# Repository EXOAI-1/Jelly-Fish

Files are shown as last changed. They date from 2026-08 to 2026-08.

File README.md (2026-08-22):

# EXO-MEDUSA — consumer print kit (Bambu Lab A1)

**Aquarium jellyfish · Ø280 × 380 mm · 360° servo · phone remote over Wi-Fi AP · 2 weekends**

This folder is the printable kit for a **Bambu Lab A1** (256 × 256 × 256 mm, 0.4 mm nozzle).
It is a dry-capsule magnetic-drive jelly: a 3-lobe cam pumps a sliding ring that bends
eight Fin-Ray tentacles in unison. No electronics in the water.

| | |
|---|---|
| Size in the tank | about **Ø 280 mm** bell, **380 mm** long |
| Printer assumed | **Bambu Lab A1**, 0.4 mm nozzle, textured PEI |
| Drive | **360° continuous servo** (DS04-NFC or MG996R 360) — not a brushless motor |
| Brain | ESP32-C3 SuperMini, SoftAP **`EXO-MEDUSA`** / `medusa123` → http://192.168.4.1 |
| Time | **2 weekends** once parts are printed (print itself is several overnight jobs) |
| Default tentacles | **TPU 95A skeleton ×8 + 0.3 mm PET film + PETG barrette ×8** |

## What's in the box

```
EXO-MEDUSA-kit/
  README.md                 ← you are here
  PARTS.csv                 file / qty / material / plate / notes
  print/
    BAMBU_A1.md             exact slicer starting points (official A1 presets)
    plates.md               how to split the bed: magnet-test → structure → TPU → dome
    EXO-MEDUSA_A1.3mf       all default STLs as named objects (open in Bambu Studio)
    stl/                    one file per part (consumer names)
    stl/aliases/            original engineering filenames (hardlinks)
    stl/optional/           OLD clamp / rib / paddle tentacle system — not the default
  docs/
    BOM.md                  buy list (Thailand), servo not Furitek
    GABARIT_FLANCS_1-1.pdf  1:1 PET-film cutting template (print at 100 %)
    TENTACLES.md            why piece 19/20 were reconstructed
  scad/                     medusa_v6, dome_flotteur, tentacle skeleton + barrette
  firmware/                 flash notes + sketch (do not start here — print first)
```

**Not in this kit (on purpose):** silicone “flesh” molds (`22_moule_*`) and the Festo AquaJellies brochure.

## Two-weekend build

**Before weekend 1 — print, in this order** (see `print/plates.md`):

1. **Magnet-test plate:** parts **01, 03, 04, 05, 07**. Glue magnets, confirm the two rotors *attract* through ~3 mm of PETG. If this fails, stop — do not print the rest yet.
2. **Structure plate:** 02 fuselage, 06 cam, 08 stator (Tree Slim supports), 09 slider, 18 ballast, 20 barrettes ×8.
3. **TPU plate:** 19 skeletons ×8 at **30 mm/s**. Print **one** first, overlay the gabarit, then the other seven.
4. **Transparent plates:** 13 dome alone, then disk + apex plug.

**Weekend 1:** magnets, axle, stator, servo in the can, cam + slider, dry pulse.

**Weekend 2:** cut 8 PET films, glue tentacles (TPU + film + barrette), hang on both rings, wire + flash, O-ring the fuselage, seal the float 24 h, 24 h capsule leak test, trim ballast, tank swim.

Assembly steps live in the notice PDF (another document). This kit is the **print + buy** front door.

## Print at a glance

| Group | Material | Parts | A1 bed |
|---|---|---|---|
| 1 magnet-test | PETG | 01, 03, 04, 05, 07 | **one plate**, all fit |
| 2 structure | PETG | 02, 06, 08, 09, 18, 20×8 | **one plate**, all fit |
| 3 TPU | TPU 95A | 19 ×8 | **one tight plate** or two of 4 |
| 4 dome | Transparent PETG | 13 dome | **own plate** (Ø160 mm) |
| 5 dome seal | Transparent PETG | 13 disk + plug | **own plate** (disk Ø145 + dome Ø160 cannot share a 256 mm bed) |

No default part exceeds 256 mm in X, Y, or Z.

Filament to buy: **1 kg PETG** (structure ~300 g printed + brim/purge/failed magnet-test), **~200 g transparent PETG** (dome + solid disk), **~50–80 g TPU 95A** (8 skeletons + brim). Official notice ballpark was 450 / 95 / 60 g — the disk is a Ø145 × 3 mm plate, so transparent mass is higher than that ballpark.

## Default vs optional tentacles

- **Default (this kit):** TPU skeleton `19_tentacle_skeleton_TPU_x8.stl` + PET 0.3 mm from the gabarit + PETG barrette `20_tentacle_bar_PETG_x8.stl`.
- **Do not print** `21_flanc_superieur_TPU` as piece 19 (wrong geometry). It is parked under `print/stl/optional/`.
- **Optional / old path:** `print/stl/optional/clamp_old_x16.stl` + `rib_old_x40.stl` + `paddle_old_x8.stl` exported from `medusa_v6.scad`. Only if you abandon the notice.

## Phone remote

After flash: join Wi-Fi **EXO-MEDUSA** / **medusa123**, open **http://192.168.4.1**. BLE Nordic UART still speaks `V50`, `V-40`, `S`, `A`, `?`, `R`. Autonomous default is 8 s swim / 4 s glide at 42 %.

## Safety (short)

N52 magnets: pinch, shatter, **lethal if swallowed**. 18650: no shorts, charge only via TP4056. CA glue: seconds. Servo 5 V from the boost, **not** through the ESP32. Wet-side magnets must be varnished. Unsealed dome → the robot inverts.

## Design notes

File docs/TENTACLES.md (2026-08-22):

# EXO-MEDUSA tentacles — TPU + PET film path (v6.2 / gabarit v6.3)

Status after this pass: **CONDITIONAL GO**. The original zip could not print notice
tentacles. This folder now has a reconstructed piece 19 + piece 20. Print **one**
TPU skeleton first, overlay the 1:1 gabarit, then print the remaining seven.

Do **not** use `21_flanc_superieur_TPU_x8.stl` as piece 19. Do **not** pour the
`22_moule_chair_silicone*.stl` trays. Do **not** print `medusa_v6.scad` clamp/rib/paddle
unless you abandon the notice path.

---

## 1. Notice quotes (étapes 0, 0b, 9, 10)

**Étape 0 — print table**

| Pièce | Orientation | Réglages |
|---|---|---|
| 19 Squelettes TPU ×8 | à plat | TPU 95A, 30 mm/s maxi, 1-2 plateaux |
| 20 Barrettes ×8 | à plat | PETG, 1 plateau |

**Étape 0b — film** (page 3): *« Chaque tentacule n'a besoin que d'UNE pièce de
film PET 0,3 mm, d'une forme simple (long trapèze + queue de poisson) : 8
découpes identiques avec le gabarit fourni (GABARIT_FLANCS_1-1.pdf). »*
Print gabarit at 100 %, control square **50,0 mm**. *« Le petit téton du bas
sera collé sur la barrette imprimée. »* Mark dashed **B1–B6** before peeling.
Qty: **8 identical films** (title says “16 flancs”; body text and gabarit
v6.3 say one film per tentacle).

**Étape 9**: *« Chaque tentacule = 1 squelette TPU imprimé (pièce 19) + 1 film
(étape 0b) + 1 barrette (pièce 20). »* Glue **14 pads** only, not spine, not
bars. Film marks B1–B6 facing the bars. Film teton into barrette **cuvette**.
*« zéro nervure à enfiler. »* Finger-press test: must curve **toward** the
finger (Fin-Ray).

**Étape 10 — hang on both rings**

1. **Anneau FIXE** (stator top): barrette teton from **below** into 8 slots + cyano.
   Films now hang from the frame.
2. **Anneau COULISSANT**: TPU skeleton teton from **below** into its 8 slots + cyano.
3. Order: 8 barrettes first → cam to sliding ring **LOW** → then skeletons.
4. Ring down → tentacles curve **inward** (power stroke), all eight together.

Curvature tweak (missing file): `tentacule_v62.scad` `sp_t = 2.6` (too soft) /
`sp_t = 1.8` (too stiff). *« 2 mm de jeu à la racine mangent la moitié de la
course. »*

---

## 2. Gabarit film — measured from PDF vectors (1 pt = 25.4/72 mm)

`GABARIT_FLANCS_1-1.pdf` page content stream, left outline. Control rectangle
width **50.00 mm**. Two copies of the same outline on one A4.

| Feature | Size (mm) |
|---|---|
| Total length (teton bottom → fishtail tip) | **212.0** |
| Root teton (glues in barrette cuvette) | **12.0 × 12.0** |
| Shoulder above teton | **16.0 wide × 40.0** |
| Main body | **30.0 wide × 126.0** |
| Fishtail outer width / tip height | **36.0 / 34.0** |
| PET thickness | **0.3** (notice + gabarit text) |
| Qty | **8** (1 per tentacle; 2 outlines/sheet) |

**B1–B6** (from teton bottom, pitch **22.40 mm**): 60.0, 82.4, 104.8, 127.2,
149.6, 172.0. Gabarit: *« ce sont les 6 lames du squelette — le film se presse
sur leur chant encollé. »* Notice étape 9 instead glues **square pads at bar
tips**. Use the notice method (pads only).

---

## 3. Part-19 verdict: `21_flanc_superieur_TPU_x8.stl` is **NOT** pièce 19

ASCII OpenSCAD mesh, 68 triangles / 36 unique vertices. Bounding box
**22.000 × 209.000 × 7.400 mm** (`x=-11..11, y=-7..202, z=0..7.4`).

Reconstructed solids:

| Feature | Size (mm) |
|---|---|
| Root plate | 22 × 14 × 3.2 |
| Male slot tab | **8.0 × 2.8 × 4.2** (z=3.2..7.4) — same as `clamp()` in `medusa_v6.scad` |
| Spine | 4.0 wide × 175 long × 2.2 thick (y=7..182) |
| Fishtail paddle | 18 wide × 20 long × 1.6 (vertices ±9,198 / 0,202) |
| Holes / slots / crossbars / pads | **none** |

Notice pièce 19 is a Fin-Ray **ladder**: spine + 6 blades + square pads + TPU
teton into the **sliding** ring. File 21 is a one-piece TPU **upper flank**
(strip + paddle + ring tab). Same tentacle scale (~210 mm), different
mechanism. Ignore 21 for the notice path.

---

## 4. `medusa_v6.scad` vs barrette / `tentacule_v62.scad`

`medusa_v6.scad` parts: `cam3 | slider | stator | clamp | rib | paddle`.
**No barrette.** Universal slots `slot_w=8.6; slot_t=3.0`. Clamp is a 14×10×12
PET-film pincer with 0.55 mm slit + 8×2.8×4.2 tab (×16). Rib ×40 comb,
paddle ×8. That is the **older two-flank clamp/rib/paddle** path. No STLs were
exported for those three. **`tentacule_v62.scad` is not anywhere in this zip.**

---

## 5. Silicone molds — ignore for tank-swim

| File | BBox (mm) |
|---|---|
| `22_moule_chair_silicone.stl` | 58 × 236 × 7.6 (cavity floor z≈2.99, rim 7.6) |
| `22_moule_chair_silicone (1).stl` | 58 × 244 × 7.6 (richer, not a byte copy) |

Notice never pours silicone on tentacles. Not pièce 19/20.

---

## 6. What to print now

| File | Qty | Material | Notes |
|---|---|---|---|
| `19_squelette_TPU_x8.stl` | 8 (print 1 first) | **TPU 95A**, 30 mm/s, à plat, pads+teton up | Reconstruction — see parameters |
| `20_barrette_PETG_x8.stl` | 8 | **PETG**, à plat, teton up | Reconstruction — cuvette 12.8×12.8×0.8 |
| PET film from gabarit | 8 | PET 0.3 mm A4 | Cut solid line; mark B1–B6 |
| `21_flanc_superieur_TPU_x8.stl` | 0 | — | **Not** piece 19 |
| `22_moule_chair_silicone*.stl` | 0 | — | Ignore |
| clamp / rib / paddle | 0 | — | Only if abandoning notice path |

### Piece 19 defaults (reconstruction)

| Param | Default | Source |
|---|---|---|
| Spine `sp_t` × `sp_w` | **2.2 × 4.0** | part 21 spine; NOTICE 1.8–2.6 band |
| Bars | **6** at pitch **22.4** | gabarit B1–B6 |
| `ring_sep` | **36** | EST from rotor z~174 / cam groove ~154 / stator ring z190 |
| `b1_y` | **24** | 60 (gabarit B1) − 36 |
| Bar span | **30** | gabarit body width |
| Pads | **3.5** sq × **1.4** rise, ×12 | EST (NOTICE says 14; gabarit has 6 blades → 12) |
| Teton | **8.0 × 2.8 × 6.2** | slot family + slider `sl_t=6` |
| Root plate | 12 × 10 × 3.2 | part 21 thickness 3.2 |
| Overall (defaults) | **30 × 154 × 9.4** | span × (root+spine) × (root 3.2+teton 6.2) |

OpenSCAD was **not** available (`apt: Unable to locate package openscad`).
The STL is a cube-union of these defaults. Edit `19_squelette_TPU_x8.scad`
and re-export on your machine after the first dry-fit.

### Piece 20 defaults

| Param | Default | Source |
|---|---|---|
| Teton | **8.0 × 2.8 × 4.5** | slot family; stator `ring_t=4` + 0.5 glue |
| Cuvette | **12.8 × 12.8 × 0.8** | gabarit 12×12 teton + 0.4/side |
| Body | **18 × 20 × 3.2** | 12 mm tab + walls; part 21 plate thickness |
| Overall | **18 × 20 × 7.7** | body 3.2 + teton 4.5 |

---

## 7. Cut-from-gabarit steps

1. Print `GABARIT_FLANCS_1-1.pdf` at **100 % / actual size**. Measure the
   control box: **50.0 mm** wide. Reprint if not.
2. Stick the sheet on 0.3 mm PET (repositionable spray or corner tape).
   One A4 = two outlines → two films.
3. Cut the **solid** line with cutter + metal rule. Keep the 12×12 mm teton
   intact.
4. Before peeling, mark **B1–B6** with a fine pen (22.4 mm pitch, first mark
   60 mm from teton bottom).
5. Repeat to **8** films. Fold test: no white crease (that would be PS, not PET).

---

## 8. Table assembly (étape 9) then hang (étape 10)

1. Skeleton flat, **pads up**. One CA drop on each pad (12 with this mesh;
   notice says 14). None on spine, none on bars.
2. Press film on in one go, B1–B6 on the bars, centred on the spine. 10 s palm.
3. Glue film 12×12 teton into barrette cuvette (blob of CA, 10 s).
4. Hang **barrettes** in the 8 stator slots from below, cyano. Cam to ring LOW.
   Then hang **skeleton tetons** in the 8 sliding-ring slots from below, cyano.
5. Dry test: turn cam by hand — eight tentacles curl inward together.

If bars miss the B marks: change `ring_sep` (hence `b1_y`) and reprint one
skeleton. If too floppy/stiff: `sp_t = 2.6` / `1.8`.

---

## 9. Go / no-go

| Question | Answer |
|---|---|
| Could they print notice tentacles **from the original zip**? | **NO-GO.** Piece 19 missing (21 is the wrong geometry). Piece 20 missing. Gabarit present. |
| Can they print tentacles **from this folder now**? | **CONDITIONAL GO.** Print 1× TPU 19 + 1× PETG 20 + 1 film, overlay gabarit, then ×8. |
| Piece 19 origin | Reconstruction (no `tentacule_v62.scad`). Parameters labeled. |
| Piece 20 origin | Reconstruction from gabarit teton + proven 8.0×2.8 slot tab. |
| Silicone / clamp-rib-paddle | Not required for first tank swim. |

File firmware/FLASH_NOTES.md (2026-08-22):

# EXO-MEDUSA v5 — flash notes (tank swim)

Board in Arduino IDE: **ESP32C3 Dev Module** (ESP32-C3 SuperMini).
Notice étape 11b: **USB CDC On Boot = Enabled**.

## Install (notice étape 11b)

1. Arduino IDE from arduino.cc
2. File → Preferences → Additional boards manager URLs:
   `https://espressif.github.io/arduino-esp32/package_esp32_index.json`
3. Boards Manager: install **esp32 by Espressif Systems** (current 3.x is fine; sketch also falls back to 2.x LEDC)
4. Tools → Board → esp32 → **ESP32C3 Dev Module**
5. Tools → **USB CDC On Boot = Enabled**
6. USB-C data cable, pick the port. If none: hold **BOOT** while plugging in, then release.
7. Open `firmware_medusa.ino` → Upload. Success looks like “Hash of data verified” / “Done uploading”.
   Failed to connect: BOOT trick again.

The notice does **not** specify flash size, frequency, partition scheme, or upload speed. Leave Arduino defaults (typically 80 MHz, QIO, 4 MB, Default 4 MB with spiffs, 921600). SuperMini is usually 4 MB.

## Libraries

- **ENABLE_LED 0 (default, tank swim):** no extra library. Built-in WiFi / BLE / LEDC only.
- If you later set `ENABLE_LED 1`: install **Adafruit NeoPixel**, **and move leak off GPIO4** (WS2812 uses GPIO4).

## Pin table (v5)

| Function | GPIO | Notes |
|---|---|---|
| Servo PWM (360° continuous) | **10** | 50 Hz, 16-bit LEDC, 1500 µs stop, ±100% → ±500 µs |
| Reed / ILS | **3** | INPUT_PULLUP to GND. Tap = run/stop or fault reset; 3 s = deep sleep |
| NTC 10k B3950 | **0** | ADC1. 10k to 3.3 V, NTC to GND |
| Vbat divider | **1** | ADC1. 100k/100k from pack + |
| Hall SS49E | **2** | ADC1. 3.3 V / GND / signal |
| Leak probe | **4** | ADC1. Was GPIO5 (not ADC on C3). 2 bare wires + 470k to 3.3 V. Analog threshold `<1200` |
| WS2812 ring | 4 (ifdef) | Off by default. Do not enable while leak is on GPIO4 |

Wi-Fi AP still `EXO-MEDUSA` / `medusa123`, page `http://192.168.4.1`. BLE Nordic UART unchanged (`V50`, `V-40`, `S`, `A`, `?`, `R`).

Rewire the leak sense from GPIO5 (notice étape 11) to **GPIO4**.

## Servo rail

Keep **470 µF** across the servo 5 V rail (long leg on +), fed from the boost, **not** through the ESP32. Brown-outs make the servo twitch without turning.

## After flash

Autonomous cycle: 8 s swim / 4 s glide at 42%. Then 24 h dry capsule leak test before a tank swim.

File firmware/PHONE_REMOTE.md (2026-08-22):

# EXO-MEDUSA phone remote (v6 kit)

The jellyfish is its own Wi-Fi access point. Your **phone browser is the remote**. No app to install. BLE remains a backup.

SoftAP: **EXO-MEDUSA** / **medusa123** → **http://192.168.4.1**

There is **no internet** on this network. That is normal. Stay on EXO-MEDUSA; the page is served by the ESP32.

## iPhone (Safari)

1. Settings → Wi-Fi → join **EXO-MEDUSA**, password **medusa123**.
2. iOS may pop a **“Log in”** captive-portal page. That *is* the remote — use it. Do not tap **Cancel** / **Use without internet** if you want the page to stay.
3. If nothing pops: open Safari and type **http://192.168.4.1** (type the address, do not search Google).
4. If Safari cannot open the page: toggle Wi-Fi off/on, rejoin, try the URL again. Turn off VPN / iCloud Private Relay for this network if DNS is hijacked.
5. Optional: Share → **Add to Home Screen** for a full-screen remote. Still just the browser.

## Android (Chrome)

1. Wi-Fi → join **EXO-MEDUSA**, password **medusa123**.
2. Android will often say **“Connected without internet”**. Stay on this network — tap the network → disable auto-switch to mobile data if the phone hops away.
3. A **Sign in to network** banner may appear — open it. Otherwise Chrome → **http://192.168.4.1**
4. If Chrome searches instead of loading: type `http://` in front of the address.

## Controls

| Control | Command |
|---|---|
| **SWIM** | Forward 55% (remote; auto resumes after 120 s idle) |
| **STOP** | Speed 0 |
| **AUTO** | Built-in 8 s swim / 4 s glide at 42% |
| **REV** | Reverse nudge (−35%) |
| Slider | −100% … +100% |
| **RESET FAULT** | Clears a fault if the leak is gone |

Live tiles (temp °C, battery V, RPM, mode, fault) poll `/status` every 1 s. No 4-second page refresh.

## BLE backup

If the AP is flaky: Android **Serial Bluetooth Terminal** (Bluetooth LE tab) or iPhone **BLE Terminal**. Device name `EXO-MEDUSA`. Text: `V50`, `V-40`, `S`, `A`, `?`, `R`. Last order wins (Wi-Fi or BLE).

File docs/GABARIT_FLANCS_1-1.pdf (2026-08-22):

## GABARIT FILM TENTACULE v6.3 — ÉCHELLE 1:1 — imprimer à 100 % — découpe ×8

1. Vérifie le carré : 50,0 mm. 2. Colle la feuille sur le film PET 0,3. 3. Découpe le trait plein (cutter + règle). 4. Marque B1-B6 au feutre :
ce sont les 6 lames du squelette — le film se presse sur leur chant encollé. Le petit téton du bas se colle sur la barrette. UNE pièce par tentacule.

CONTRÔLE : 50,0 mm →

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
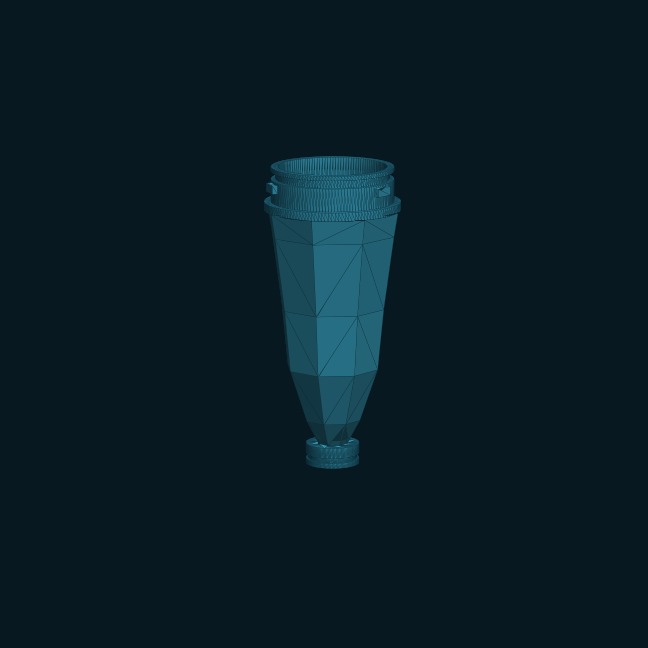
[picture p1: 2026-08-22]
docs/img/02_fuselage.png

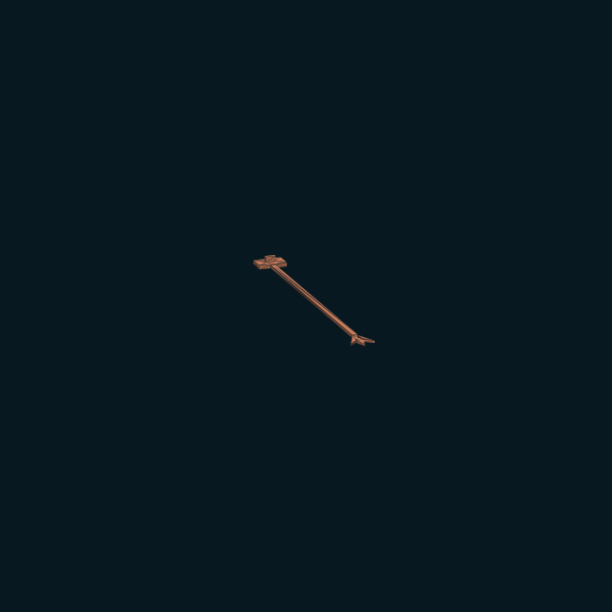
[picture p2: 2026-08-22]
docs/img/19_tpu_paddle.png

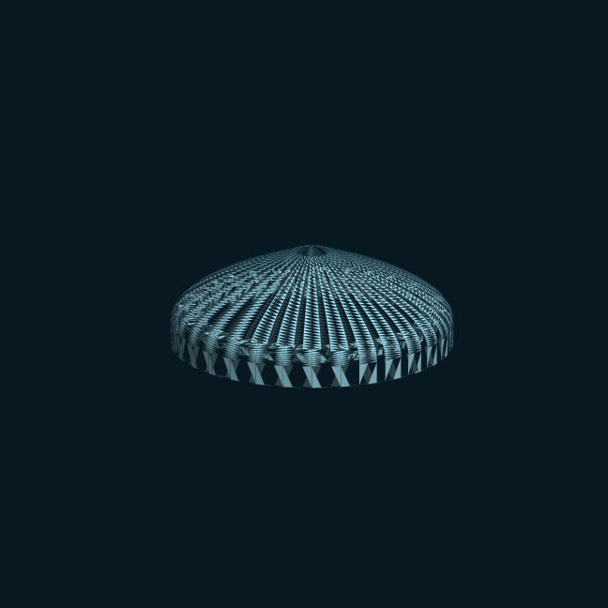
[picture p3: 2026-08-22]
docs/img/13_dome.png

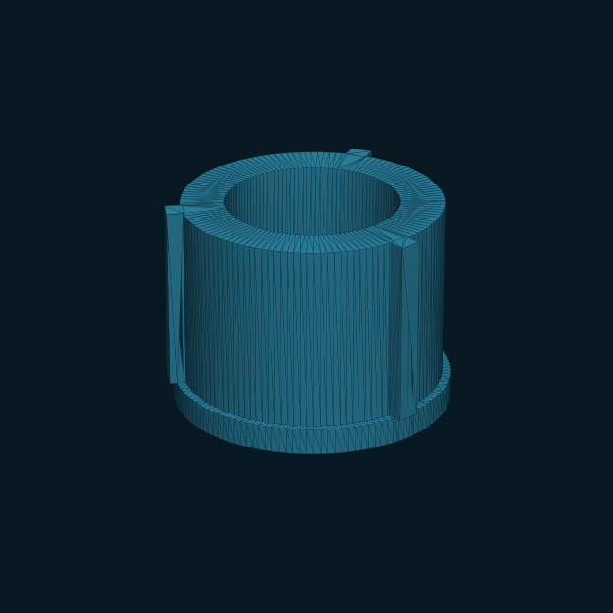
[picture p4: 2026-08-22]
docs/img/05_rotor_outer.png

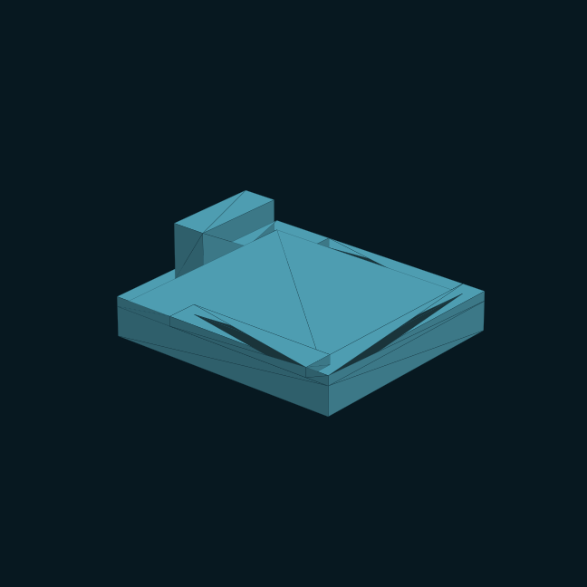
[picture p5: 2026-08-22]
docs/img/20_barrette.png

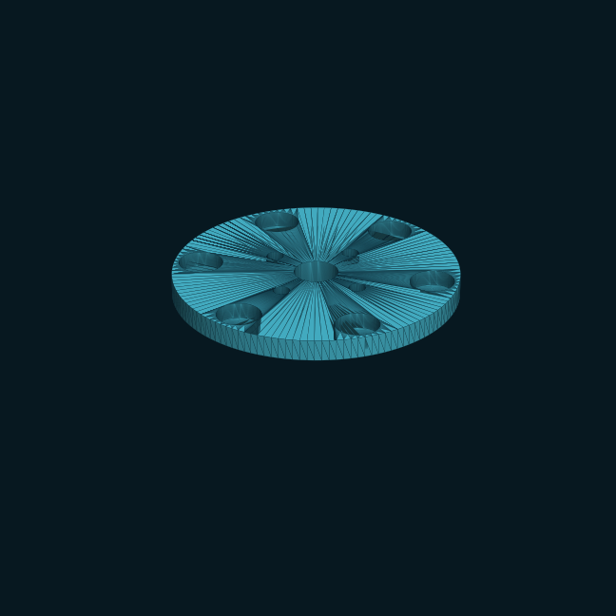
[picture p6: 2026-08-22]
docs/img/04_rotor_inner.png

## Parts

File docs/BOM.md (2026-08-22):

# EXO-MEDUSA — bill of materials (v1 tank swim)

Drive is a **360° continuous servo**, **not** the Furitek Mini-Komodo.
Skip: LED ring, SG90 pendulum, Qi wireless, silicone “flesh” molds.

Prices in THB are from `Meca_Jellyfish_BOM_Thailand.xlsx` except the servo (that spreadsheet had the wrong motor). Search column is Lazada / Shopee TH.

## Buy (electronics)

| What | Qty | Search | ~THB |
|---|---|---|---|
| 360° continuous servo (DS04-NFC or MG996R 360) | 1 | `DS04-NFC 360` or `MG996R 360 continuous` | — (not in the old BOM) |
| ESP32-C3 SuperMini | 1 | ESP32-C3 SuperMini | 105 |
| 18650 + holder (3000 mAh) | 1 | 18650 battery holder | 140 |
| TP4056 with protection (DW01) | 1 | TP4056 protection | 35 |
| 5 V boost ≥2 A (MT3608) | 1 | MT3608 boost 5V | 35 |
| 470 µF 10 V electrolytic | 1 | 470uF electrolytic | 17.5 |
| SS49E linear Hall | 1 | SS49E hall sensor | 17.5 |
| NTC 10k B3950 | 1 | NTC 10k 3950 | 17.5 |
| Reed switch + magnet | 1 | reed switch glass | 35 |
| Resistors: 10k ×1, 100k ×2, 470k ×1 | 1 kit | resistor kit | 35 |

Servo 5 V goes through the boost, **not** through the ESP32. 470 µF sits across the servo 5 V rail.

## Buy (mechanics / consumables)

| What | Qty | Search | ~THB |
|---|---|---|---|
| N52 magnets 8×3 mm | 12 | N52 8x3 magnet | 105 |
| N52 magnets 5×2 mm | 2 | N52 5x2 magnet | 35 |
| NBR O-ring ~53×3 mm | 1 | o-ring 53x3 | 35 |
| Silicone grease | 1 | silicone grease plumbing | 70 |
| PET film 0.3 mm A4 | 10 sheets | PET sheet 0.3mm A4 | 70 |
| M3 screws: 16 mm ×2, 10 mm ×3, 8 mm ×5 | 1 kit | M3 screw kit | 70 |
| Fishing sinkers / steel balls ~40 g | 1 | fishing sinkers split shot | 70 |
| Aquarium silicone 100% clear, **no fungicide** | 1–2 | aquarium silicone sealant clear 100% | 175 |
| 5-min epoxy | 1 | epoxy glue 5 minutes | 70 |
| CA glue (cyanoacrylate) | 1 | super glue CA | — (notice uses it everywhere; not in the old BOM) |
| Thermal pad + a bit of foam | 1 | thermal pad servo | — (notice étape 6) |
| Nail varnish (wet-side magnets) | 1 | — | household |

Cut the 8 tentacle films with `docs/GABARIT_FLANCS_1-1.pdf` printed at **100 %** (50.0 mm control square).

## Print (filament)

| What | ~mass (printed) | Buy | Use |
|---|---|---|---|
| PETG | ~300 g structure + bars (buy **1 kg**) | Generic PETG | capsule, stator, cam, ring, axle, rotors, barrettes ×8 |
| Transparent PETG | ~140 g (buy a small spool) | PETG Translucent | float dome + disk + plug |
| TPU 95A | ~30 g skeletons ×8 (buy **≥ 100 g**) | TPU 95A | tentacle skeletons; 30 mm/s; external spool |

Masses are STL-volume estimates; brim / purge / a failed plate are extra. The old notice ballpark (450 / 95 / 60 g) is fine as a shopping ceiling.

## Do not buy for v1 swim

- Furitek Mini-Komodo (wrong motor for this firmware)
- WS2812 8-LED ring
- SG90 (pendulum steering — v6.1, not this kit)
- Qi wireless TX/RX
- Silicone tentacle molds (`22_moule_*`)

Priced hardware rows above ≈ **1060 THB + servo + filament + CA / thermal pad**.

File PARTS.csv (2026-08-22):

file | qty | material | plate_group | bbox_mm | notes | original_name
01_capsule_upper.stl | 1 | PETG | 1_magnet_test | 66.0x66.0x66.0 | Magnet-test first. Dry capsule upper can. | 01b_bidon_sup.stl
02_fuselage.stl | 1 | PETG | 2_structure | 66.0x66.0x147.0 | O-ring groove in the collar. Do not print with 01 on first plate. | 02b_fuselage.stl
03_stub_axle.stl | 1 | PETG | 1_magnet_test | 26.0x26.0x48.5 | Magnet-test. Bolts to can roof. | 03_stub_axle.stl
04_rotor_inner.stl | 1 | PETG | 1_magnet_test | 54.0x54.0x12.0 | Magnet-test. 6× N52 8×3 pockets. | 04_rotor_inner.stl
05_rotor_outer.stl | 1 | PETG | 1_magnet_test | 64.0x65.5x48.0 | Magnet-test. Wet-side rotor + Hall pips + cam keys. | 05_rotor_cup.stl
06_cam_3lobe.stl | 1 | PETG | 2_structure | 78.0x78.0x40.0 | 3-lobe groove, 10 mm stroke. Sand burrs in the groove. | 06s_came_3lobes.stl
07_top_cap.stl | 1 | PETG | 1_magnet_test | 30.0x30.0x3.0 | Magnet-test. 1× M3×8. | 07_top_cap.stl
08_stator.stl | 1 | PETG | 2_structure | 126.0x126.0x99.0 | ONLY part that needs supports. Tree Slim, not normal. | 08s_stator_v6.stl
09_slider_ring.stl | 1 | PETG | 2_structure | 112.6x110.0x14.0 | 3 pins ride the cam groove. 8 tentacle slots. | 09s_anneau_coulissant.stl
13_float_dome.stl | 1 | Transparent PETG | 4_dome | 160.0x160.0x53.0 | Own plate — 160 mm Ø. Extra outer walls. Ironing optional. | 13e_dome_flotteur.stl
13_float_disk.stl | 1 | Transparent PETG | 5_dome_seal | 145.0x145.0x3.0 | Glues on internal shoulder, sealed ~195 cm³ chamber. | 13f_disque_flotteur.stl
13_float_plug.stl | 1 | Transparent PETG | 5_dome_seal | 30.0x30.0x6.0 | Apex plug / oculus. Same plate as disk. | 13g_bouchon_apex.stl
18_ballast_trellis.stl | 1 | PETG | 2_structure | 33.0x33.0x60.0 | Holds ~40 g fishing sinkers. | 18_treillis_lest.stl
19_tentacle_skeleton_TPU_x8.stl | 8 | TPU 95A | 3_tpu | 30.0x154.0x9.4 | Default tentacle path. Print ONE first, overlay gabarit, then ×8. External spool. | 19_squelette_TPU_x8.stl (reconstruction; NOT 21)
20_tentacle_bar_PETG_x8.stl | 8 | PETG | 2_structure | 18.0x20.0x7.7 | Fits leftover space on structure plate. 8.0×2.8 tab into stator slots. | 20_barrette_PETG_x8.stl (reconstruction)
optional/clamp_old_x16.stl | 16 | PETG | optional_legacy | 14x10x16.2 | OLD tentacle clamp. Not the default kit path. | medusa_v6.scad clamp
optional/rib_old_x40.stl | 40 | PETG | optional_legacy | 20x18x2.5 | OLD tentacle rib/comb. Not the default kit path. | medusa_v6.scad rib
optional/paddle_old_x8.stl | 8 | PETG | optional_legacy | ~36x34x2.2 | OLD tentacle paddle. Not the default kit path. | medusa_v6.scad paddle
optional/legacy_21_flanc_TPU_NOT_piece19.stl | 0 | TPU 95A | do_not_print | 22x209x7.4 | Original file 21. Wrong geometry for notice piece 19. Do not print as skeleton. | 21_flanc_superieur_TPU_x8.stl

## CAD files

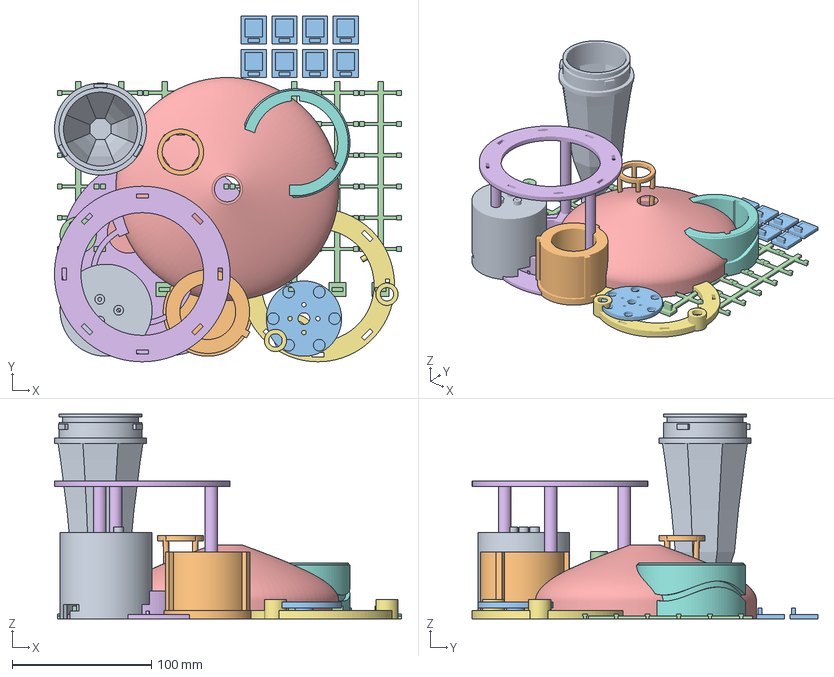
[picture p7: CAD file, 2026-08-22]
print/EXO-MEDUSA_A1.3mf
249.0 x 248.0 x 147.0 mm
01_capsule_upper
05_rotor_outer
04_rotor_inner
03_stub_axle
07_top_cap
08_stator
09_slider_ring
06_cam_3lobe
02_fuselage
18_ballast_trellis
20_tentacle_bar_PETG x 8
19_tentacle_skeleton_TPU x 8
13_float_dome
13_float_disk
13_float_plug

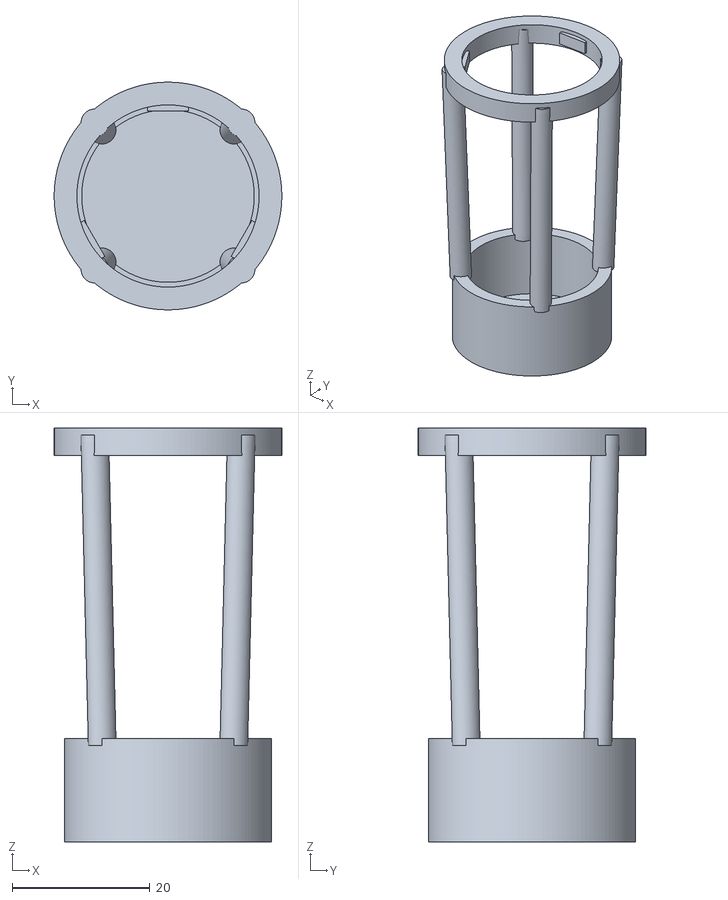
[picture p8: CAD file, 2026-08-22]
print/stl/18_ballast_trellis.stl
33.0 x 33.0 x 60.0

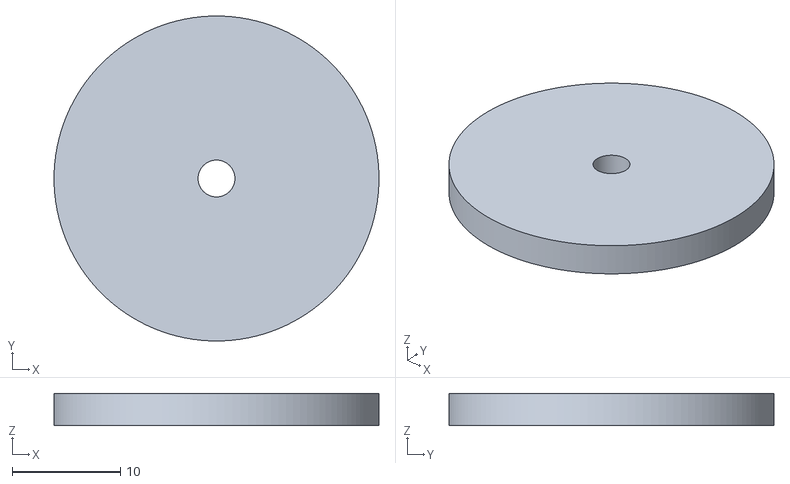
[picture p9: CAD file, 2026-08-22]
print/stl/07_top_cap.stl
30.0 x 30.0 x 3.00

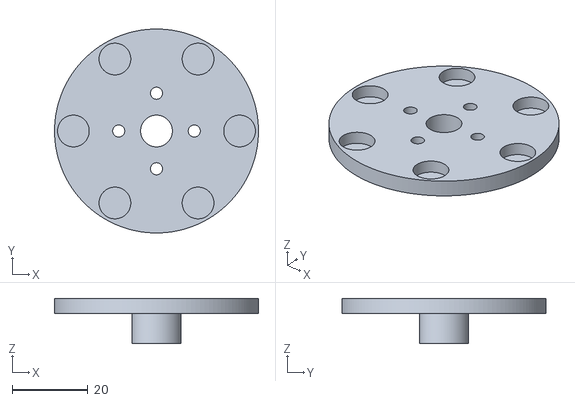
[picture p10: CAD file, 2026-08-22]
print/stl/aliases/04_rotor_inner.stl
54.0 x 54.0 x 12.0

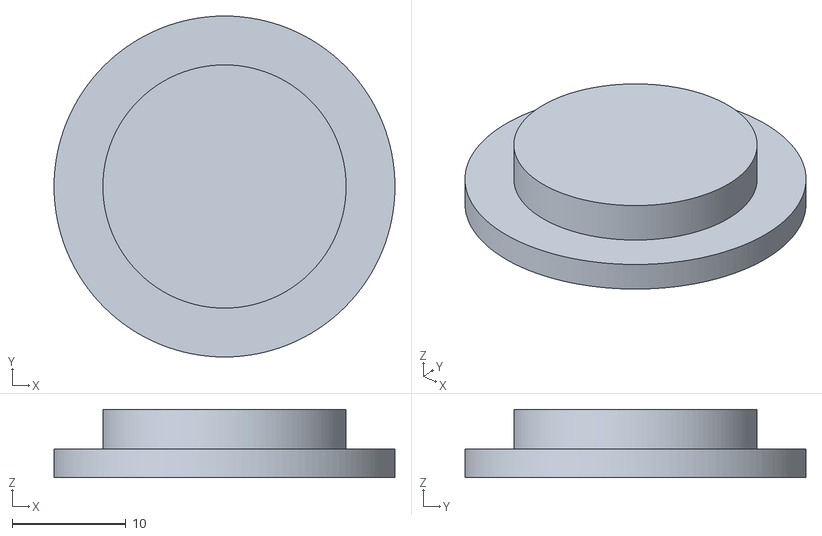
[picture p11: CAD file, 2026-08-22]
print/stl/aliases/13g_bouchon_apex.stl
30.0 x 30.0 x 6.00

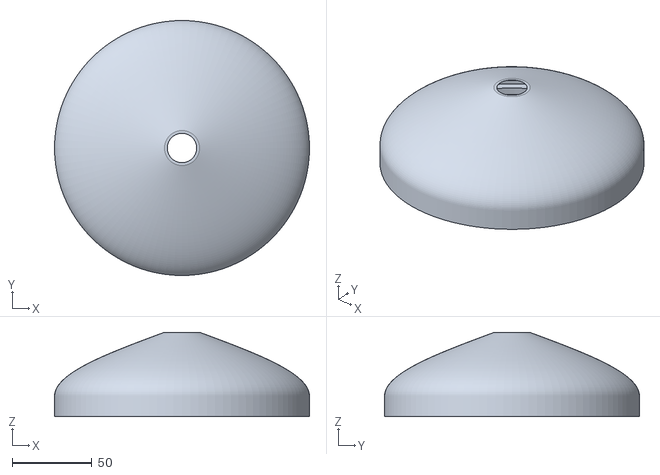
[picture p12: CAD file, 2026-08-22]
print/stl/13_float_dome.stl
160.0 x 160.0 x 53.0

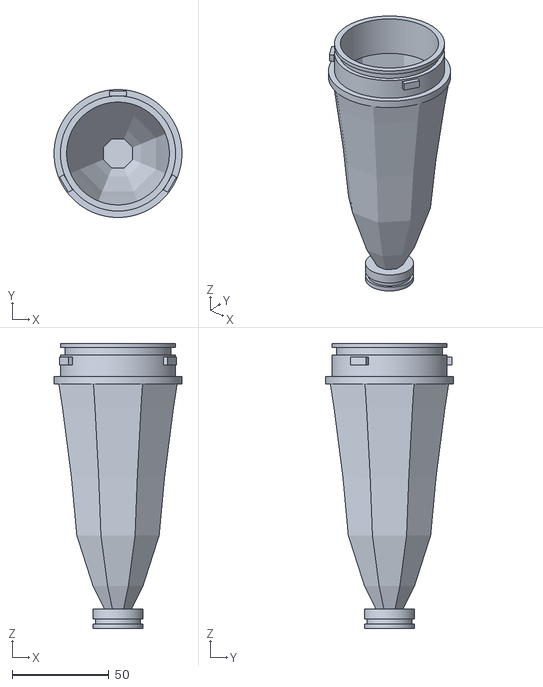
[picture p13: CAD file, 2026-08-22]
print/stl/aliases/02b_fuselage.stl
66.0 x 66.0 x 147.0

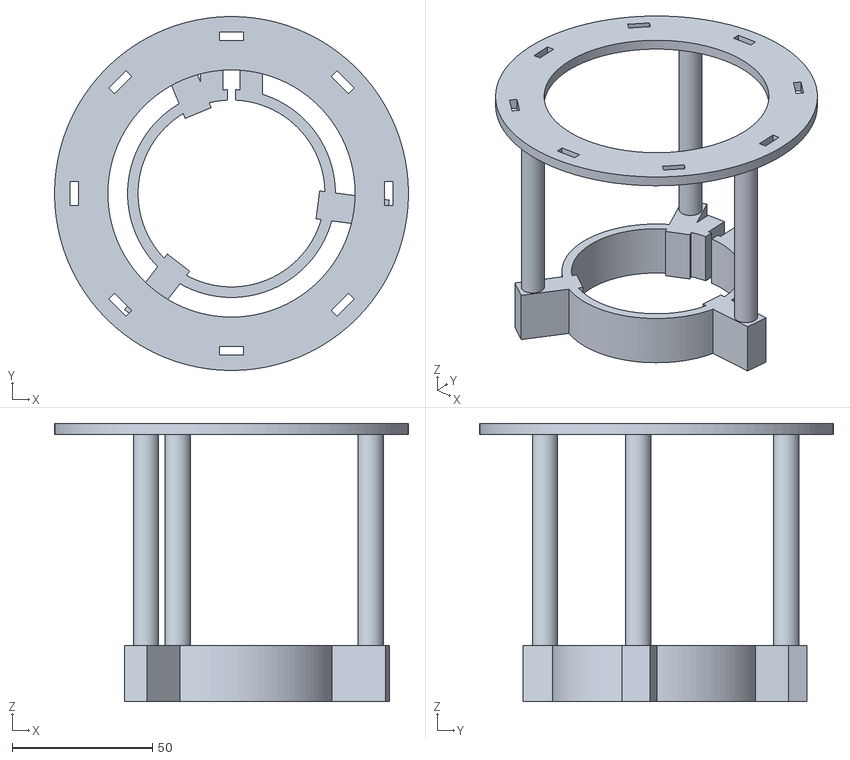
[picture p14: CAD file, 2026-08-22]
print/stl/aliases/08s_stator_v6.stl
126.0 x 126.0 x 99.0

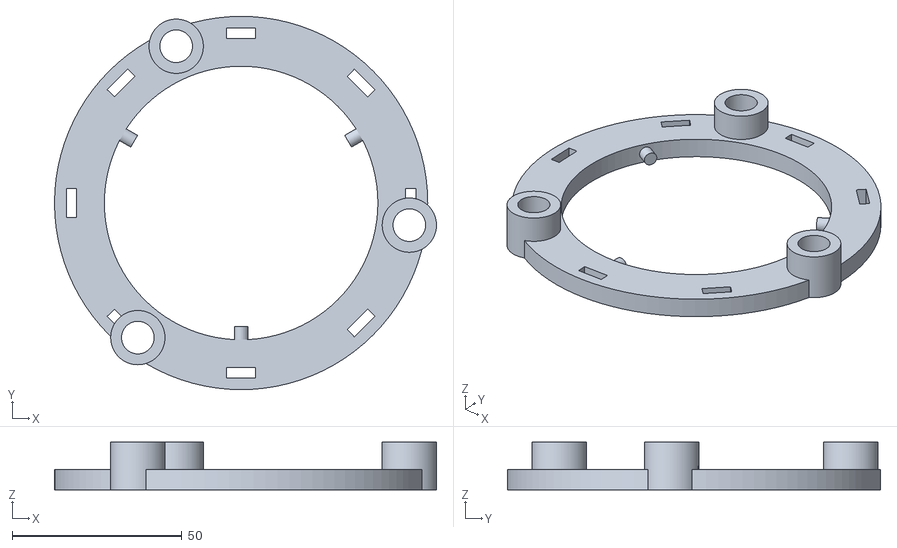
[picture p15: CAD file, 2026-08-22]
print/stl/09_slider_ring.stl
112.6 x 110.0 x 14.0

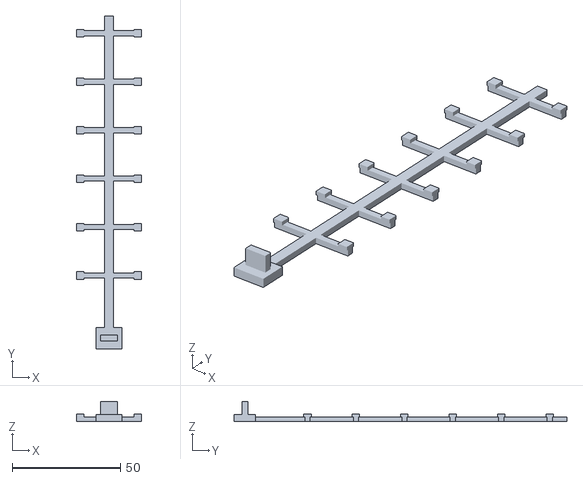
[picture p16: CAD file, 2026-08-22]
print/stl/19_tentacle_skeleton_TPU_x8.stl
30.0 x 154.0 x 9.40

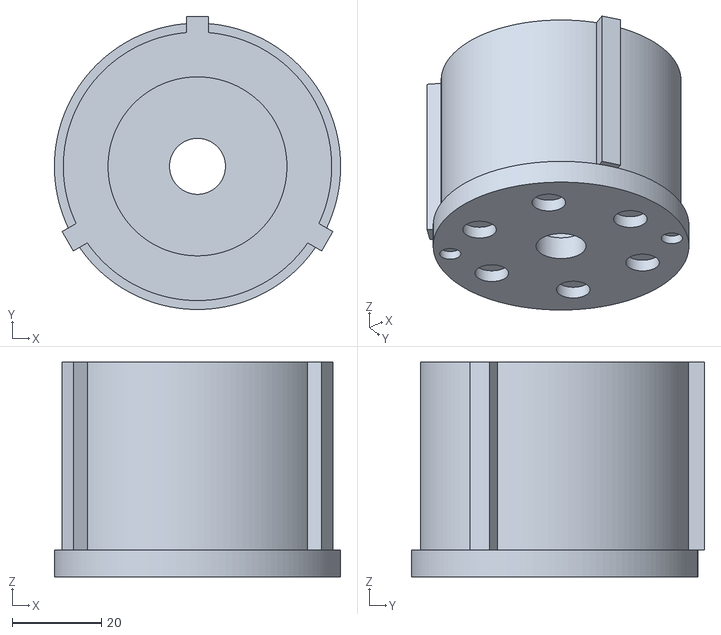
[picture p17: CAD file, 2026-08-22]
print/stl/aliases/05_rotor_cup.stl
64.0 x 65.5 x 48.0

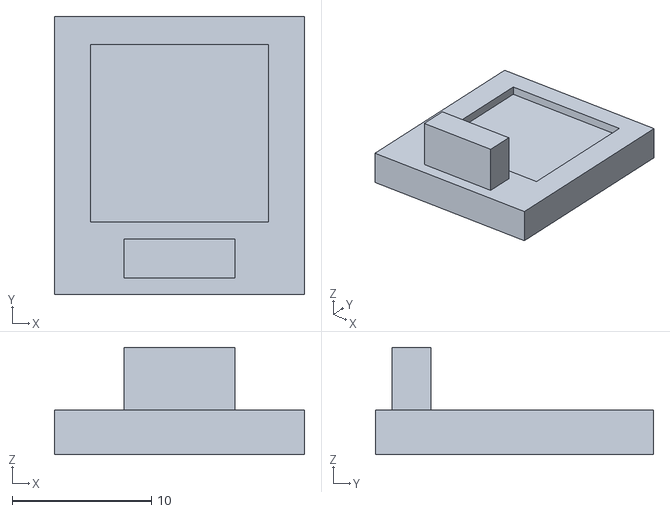
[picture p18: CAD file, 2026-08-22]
print/stl/20_tentacle_bar_PETG_x8.stl
18.0 x 20.0 x 7.70

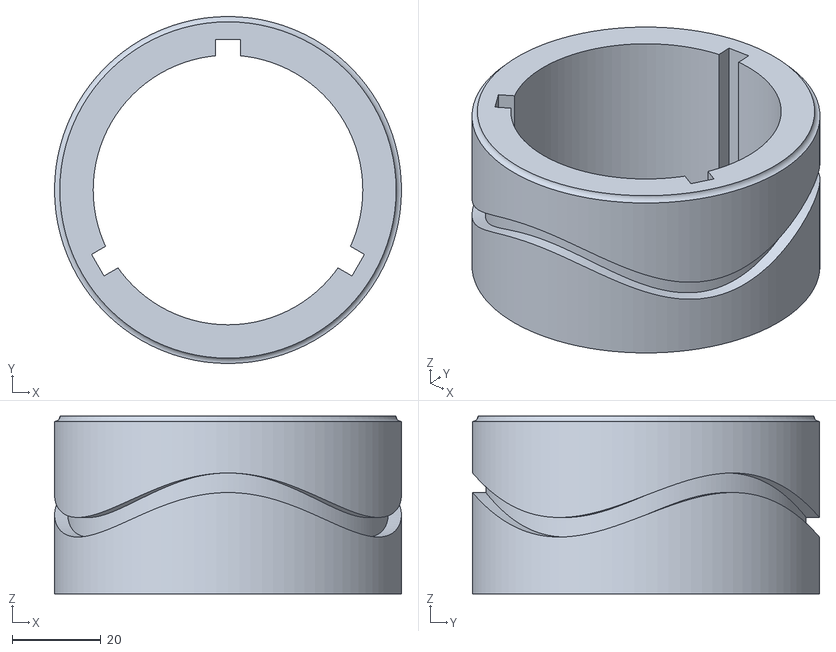
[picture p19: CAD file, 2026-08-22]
print/stl/aliases/06s_came_3lobes.stl
78.0 x 78.0 x 40.0

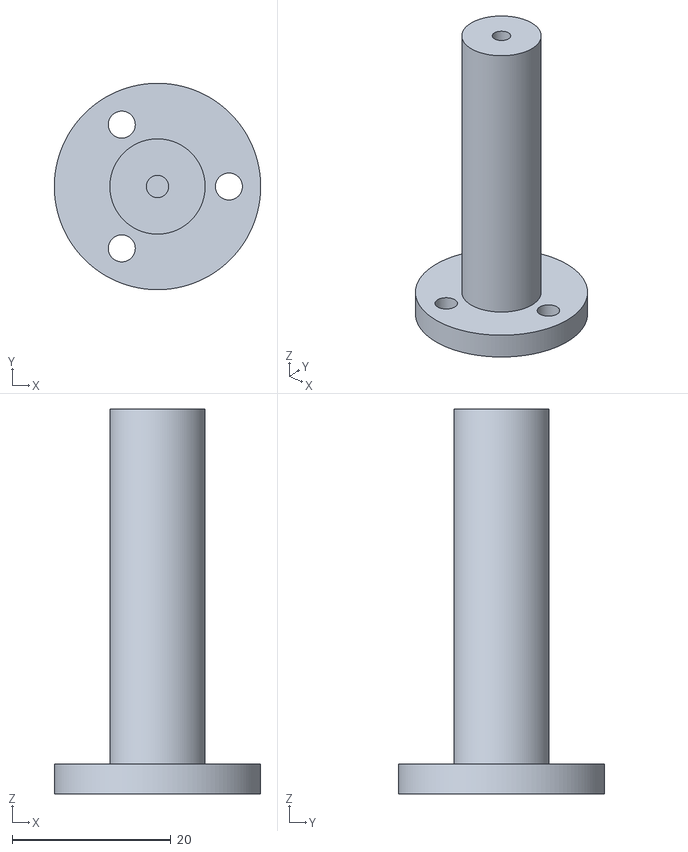
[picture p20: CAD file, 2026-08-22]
print/stl/03_stub_axle.stl
26.0 x 26.0 x 48.5

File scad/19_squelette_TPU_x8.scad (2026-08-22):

// 19_squelette_TPU_x8.scad
// EXO-MEDUSA v6.2 — piece 19 "squelette TPU" x8  (Fin-Ray ladder)
//
// THIS IS A RECONSTRUCTION. tentacule_v62.scad is NOT in the zip.
// 21_flanc_superieur_TPU_x8.stl is a one-piece TPU flank (strip+paddle+slot tab),
// NOT this skeleton — do not print 21 as piece 19.
//
// Print: TPU 95A, a plat, 30 mm/s max, x8, 1-2 plates. (NOTICE etape 0)
// First print ONE, overlay GABARIT_FLANCS_1-1.pdf, then tweak b1_y / sp_t.
//
// openscad -o 19_squelette_TPU_x8.stl 19_squelette_TPU_x8.scad

/* [spine — NOTICE etape 10 sp_t band; thickness from part 21] */
sp_t = 2.2;           // mm  SOURCE part 21 spine z=2.2. NOTICE: 2.6 too soft, 1.8 too stiff
sp_w = 4.0;           // mm  SOURCE part 21 spine x=-2..2

/* [bars — GABARIT_FLANCS_1-1.pdf v6.3] */
n_bars    = 6;    // gabarit "6 lames" B1-B6. NOTICE "14 patins" would be 7; keep 6.
bar_pitch = 22.4; // mm  SOURCE gabarit B spacing (63.4962 pt = 22.40 mm)
b1_film   = 60.0;   // mm  SOURCE gabarit B1 from film teton bottom
ring_sep  = 36.0;  // mm  EST vertical+radial gap barrette ring -> slider ring
                         //     (rotor cup z~174, cam groove ~z154, stator ring z190, dr=6)
b1_y      = b1_film - ring_sep;  // = 24.0 mm with defaults
bar_span  = 30.0;  // mm  SOURCE gabarit film body width 30.00
bar_w     = 2.4;     // mm  EST printable TPU rib width
bar_t     = 2.2;     // mm  same layer as spine

/* [pads — NOTICE etape 9 "patins carres", glue ONLY here] */
pad   = 3.5;           // mm  EST "petits patins carres"
pad_h = 1.4;         // mm  EST rise so film does not touch spine/bars

/* [root teton — sliding ring 09s, fentes 8.6 x 3.0 x sl_t=6] */
tab_w = 8.0;         // SOURCE medusa_v6.scad clamp tab_w / part 21
tab_t = 2.8;         // SOURCE tab_t 2.8
tab_h = 6.2;      // sl_t=6 + 0.2 glue. NOTICE: 2 mm play eats half the stroke
root_w = 12.0;
root_l = 10.0;
root_h = 3.2;       // SOURCE part 21 root plate 3.2
tail   = 8.0;         // mm  EST past B6

$fn = 24;

module squelette() {
    // root plate
    translate([-root_w/2, 0, 0]) cube([root_w, root_l, root_h]);
    // teton (+Z) — insert from below into anneau coulissant
    translate([-tab_w/2, (root_l-tab_t)/2, root_h]) cube([tab_w, tab_t, tab_h]);
    // spine
    spine_len = b1_y + (n_bars-1)*bar_pitch + tail;
    translate([-sp_w/2, root_l, 0]) cube([sp_w, spine_len, sp_t]);
    // bars + pads
    arm = (bar_span - sp_w)/2;
    for (i=[0:n_bars-1]) {
        y = root_l + b1_y + i*bar_pitch;
        translate([-bar_span/2, y-bar_w/2, 0]) cube([arm, bar_w, bar_t]);
        translate([ sp_w/2,     y-bar_w/2, 0]) cube([arm, bar_w, bar_t]);
        for (s=[-1,1])
            translate([s*(bar_span/2-pad/2)-pad/2, y-pad/2, bar_t])
                cube([pad, pad, pad_h]);
    }
}

squelette();

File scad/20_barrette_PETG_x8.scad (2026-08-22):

// 20_barrette_PETG_x8.scad
// EXO-MEDUSA v6.2 — piece 20 "barrette racine" PETG x8
//
// Hangs the PET 0.3 mm film from the FIXED stator ring (NOTICE etape 10).
// Film 12 x 12 mm root tab (GABARIT) glues into the cuvette.
// Male teton is the 8.0 x 2.8 family that fits fentes 8.6 x 3.0.
//
// Print: PETG, a plat (body on bed, teton up), x8, 1 plate. (NOTICE etape 0)
//
// openscad -o 20_barrette_PETG_x8.stl 20_barrette_PETG_x8.scad

/* [slot teton — FIXED ring 08s, ring_t=4, fentes 8.6 x 3.0] */
tab_w = 8.0;         // SOURCE medusa_v6.scad clamp tab_w / part 21
tab_t = 2.8;         // SOURCE 2.8
tab_h = 4.5;      // ring_t=4 + 0.5 mm so a glue fillet sits on the ring

/* [cuvette — GABARIT_FLANCS_1-1.pdf film teton] */
film_tet_w = 12.0; // mm  SOURCE gabarit teton width 12.00 (34.0158 pt)
film_tet_l = 12.0; // mm  SOURCE gabarit teton length 12.00
cuvette_clear = 0.4; // mm/side glue gap
cuvette_d = 0.8;     // mm  pocket depth (film is 0.3)
cuvette_w = film_tet_w + 2*cuvette_clear;  // 12.8
cuvette_l = film_tet_l + 2*cuvette_clear;

/* [body] */
body_w = 18.0;       // mm  across (12 mm teton + walls)
body_l = 20.0;       // mm  along tentacle
body_h = 3.2;       // mm  SOURCE part 21 root plate 3.2
inboard = 1.2;     // mm  plastic inboard of teton
gap_tc  = 1.2;      // mm  teton -> cuvette

$fn = 24;

module barrette() {
    cuv_y0 = inboard + tab_t + gap_tc;
    difference() {
        translate([-body_w/2, 0, 0]) cube([body_w, body_l, body_h]);
        // cuvette open to +Z, outboard of teton
        translate([-cuvette_w/2, cuv_y0, body_h-cuvette_d])
            cube([cuvette_w, cuvette_l, cuvette_d+0.1]);
    }
    // teton +Z — insert from below into anneau FIXE (stator)
    translate([-tab_w/2, inboard, body_h]) cube([tab_w, tab_t, tab_h]);
}

barrette();

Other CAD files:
print/stl/01_capsule_upper.stl
print/stl/13_float_disk.stl
print/stl/aliases/01b_bidon_sup.stl
print/stl/aliases/13f_disque_flotteur.stl
print/stl/optional/clamp_old_x16.stl
print/stl/optional/legacy_21_flanc_TPU_NOT_piece19.stl
print/stl/optional/paddle_old_x8.stl
print/stl/optional/rib_old_x40.stl
scad/dome_flotteur.scad
scad/medusa_v6.scad

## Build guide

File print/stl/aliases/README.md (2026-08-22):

# Original filenames

Hardlinks to the consumer-named STLs in the parent folder, using the engineering names from the v6 zip.

| Alias (this folder) | Consumer name |
|---|---|
| 01b_bidon_sup.stl | 01_capsule_upper.stl |
| 02b_fuselage.stl | 02_fuselage.stl |
| 03_stub_axle.stl | 03_stub_axle.stl |
| 04_rotor_inner.stl | 04_rotor_inner.stl |
| 05_rotor_cup.stl | 05_rotor_outer.stl |
| 06s_came_3lobes.stl | 06_cam_3lobe.stl |
| 07_top_cap.stl | 07_top_cap.stl |
| 08s_stator_v6.stl | 08_stator.stl |
| 09s_anneau_coulissant.stl | 09_slider_ring.stl |
| 13e_dome_flotteur.stl | 13_float_dome.stl |
| 13f_disque_flotteur.stl | 13_float_disk.stl |
| 13g_bouchon_apex.stl | 13_float_plug.stl |
| 18_treillis_lest.stl | 18_ballast_trellis.stl |
| 19_squelette_TPU_x8.stl | 19_tentacle_skeleton_TPU_x8.stl |
| 20_barrette_PETG_x8.stl | 20_tentacle_bar_PETG_x8.stl |

File `21_flanc_superieur_TPU_x8.stl` is **not** aliased here. It is the wrong geometry for notice piece 19; see `../optional/legacy_21_flanc_TPU_NOT_piece19.stl`.

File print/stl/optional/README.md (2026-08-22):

# Optional / old tentacle system

**Default kit path:** TPU skeleton + 0.3 mm PET film + PETG barrette.
Files in this folder are **not** on the default plates.

| File | Qty | What |
|---|---|---|
| `clamp_old_x16.stl` | 16 | PET-film pincer, 0.55 mm slot, 8.0×2.8 tab → 8.6×3.0 ring slots. Exported from `medusa_v6.scad` `clamp`. |
| `rib_old_x40.stl` | 40 | Comb rib, 0.6 mm slits at 12 mm flank gap. `rib`. |
| `paddle_old_x8.stl` | 8 | Caudal paddle. `paddle`. |
| `legacy_21_flanc_TPU_NOT_piece19.stl` | 0 | Original `21_flanc_superieur_TPU_x8.stl`. One-piece TPU flank + paddle + tab. **Not** notice pièce 19. |

Exported with OpenSCAD 2021.01 from `scad/medusa_v6.scad`:

```
openscad -D 'part="clamp"'  -o clamp_old_x16.stl  medusa_v6.scad
openscad -D 'part="rib"'    -o rib_old_x40.stl    medusa_v6.scad
openscad -D 'part="paddle"' -o paddle_old_x8.stl  medusa_v6.scad
```

Print these only if you deliberately drop the v6.2 film+skeleton notice and go back to two PET flanks pinched in clamps.

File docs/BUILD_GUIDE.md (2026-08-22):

# EXO-MEDUSA Build Guide

**Consumer kit v6 · Bambu Lab A1**

A first tank-swim jellyfish. English. Short steps. Print this PDF twin at
`docs/EXO-MEDUSA_Build_Guide.pdf`. Do not change the STLs or the firmware.

---

## What you are building

You are building **EXO-MEDUSA**: an aquarium jellyfish about **Ø 280 × 380 mm**.

A dry electronics capsule sits in the middle. A 360° servo turns magnets
*inside* the can. Matching magnets *outside* follow through the wall. A
3-lobe cam then pumps a sliding ring **10 mm**, three times per turn. The
ring bends **eight tentacles** inward together. That pulse is the swim.

- Your **phone browser is the remote**. No app.
- There is **no steering**. It pulses and drifts. That is this kit.
- **No electrical part lives in the water.** The servo, battery, and ESP32
  stay dry inside the capsule.
- Firmware is **v6**. Leak sense is on **GPIO4** (not GPIO5 from the old
  French notice).

Drive is a **360° continuous servo**: **DS04-NFC** or **MG996R 360**. Not a
Furitek brushless motor. Not an ESC.

Tentacles in this kit are a **TPU paddle** (the original zip’s file 21,
22 × 209 mm) plus a **PET film** plus a **PETG barrette**. Kit path:
`print/stl/optional/legacy_21_flanc_TPU_NOT_piece19.stl` ×8, and
`print/stl/20_tentacle_bar_PETG_x8.stl` ×8 (alias `20_barrette_PETG_x8.stl`).
That paddle is not the missing Fin-Ray ladder from the French notice. It
still fits the 8.6 × 3.0 mm slots and will pulse in a tank. Do not print
`19_tentacle_skeleton_TPU_x8.stl` for these steps — different mesh.

Budget two weekends. One screwdriver. Super glue. A Bambu Lab A1.

---

## Safety — read this first

**N52 magnets.** They pinch hard and chip if they slam together. Keep them
away from children. **A swallowed N52 magnet is lethal.** Two magnets (or
one magnet and a metal object) can trap bowel. This is not a toy drawer.

**18650 cells.** Never short the + and − tabs. Never puncture. Charge only
through the **TP4056** module. No bare-cell chargers.

**CA glue (cyanoacrylate).** It bonds skin in about five seconds. Ventilate.
Have acetone or a CA debonder nearby. Not near eyes.

**Servo 5 V.** The servo red wire goes to the **boost 5 V output**. Do **not**
feed servo current through the ESP32. The ESP32 may share that same 5 V rail.
A **470 µF** capacitor sits across the servo 5 V (long leg on +). Missing
that cap is why a servo twitches and will not turn.

**Aquarium silicone.** 100 % clear. **No fungicide. No anti-mould.** Bathroom
silicone can kill fish and is the wrong tube.

**Bayonet lid.** Never force it. If it fights you, a wire is on the O-ring.

**Wet-side magnets.** The outer rotor lives in water. Nickel plating is not
enough. Coat every glued magnet with nail varnish or a thin epoxy film.

**Unsealed float dome.** If the dome leaks, the robot inverts. The dome is
the float, not decoration.

---

## What you need

Buy on Lazada / Shopee Thailand (or anywhere). Search terms below. Prices
are ballpark THB from the kit shop list, **except the servo** (the old BOM
had the wrong motor).

### Electronics

| What | Qty | Search | ~THB |
|---|---|---|---|
| 360° continuous servo (DS04-NFC or MG996R 360) | 1 | `DS04-NFC 360` or `MG996R 360 continuous` | — |
| ESP32-C3 SuperMini | 1 | ESP32-C3 SuperMini | 105 |
| 18650 + holder (3000 mAh) | 1 | 18650 battery holder | 140 |
| TP4056 **with protection** (DW01) | 1 | TP4056 protection | 35 |
| 5 V boost ≥ 2 A (MT3608) | 1 | MT3608 boost 5V | 35 |
| 470 µF 10 V electrolytic | 1 | 470uF electrolytic | 17.5 |
| SS49E linear Hall | 1 | SS49E hall sensor | 17.5 |
| NTC 10k B3950 | 1 | NTC 10k 3950 | 17.5 |
| Reed switch + a small magnet | 1 | reed switch glass | 35 |
| Resistors: 10k ×1, 100k ×2, 470k ×1 | 1 kit | resistor kit | 35 |

Servo 5 V comes from the boost, **not** through the ESP32. 470 µF sits
across that servo 5 V rail.

### Mechanics and glue

| What | Qty | Search | ~THB |
|---|---|---|---|
| N52 magnets 8 × 3 mm | 12 | N52 8x3 magnet | 105 |
| N52 magnets 5 × 2 mm | 2 | N52 5x2 magnet | 35 |
| NBR O-ring ~53 × 3 mm | 1 | o-ring 53x3 | 35 |
| Silicone grease (plumbing, not automotive) | 1 | silicone grease plumbing | 70 |
| PET film 0.3 mm A4 | 10 sheets | PET sheet 0.3mm A4 | 70 |
| M3 screws: 16 mm ×2, 10 mm ×3, 8 mm ×5 | 1 kit | M3 screw kit | 70 |
| Fishing sinkers ~40 g | 1 | fishing sinkers split shot | 70 |
| Aquarium silicone 100 % clear, **no fungicide** | 1–2 | aquarium silicone sealant clear 100% | 175 |
| 5-minute epoxy | 1 | epoxy glue 5 minutes | 70 |
| CA glue (super glue) | 1 | super glue CA | — |
| Thermal pad + a bit of foam | 1 | thermal pad servo | — |
| Nail varnish (wet-side magnets) | 1 | household | — |

Plus a PH1 screwdriver, cutter, metal rule, basic soldering iron, USB-C
**data** cable (not charge-only).

### Filament (Bambu Lab A1)

| Filament | ~mass | Use |
|---|---|---|
| PETG | ~450 g | capsule, stator, cam, ring, axle, rotors, barrettes |
| Transparent PETG | ~95 g | float dome 13e / disk 13f / plug 13g |
| TPU 95A | ~60 g | tentacle paddles ×8 (file 21) |

### Do not buy for this first swim

- Furitek Mini-Komodo (wrong drive)
- WS2812 LED ring
- SG90 (pendulum steering is not in this firmware)
- Qi wireless TX/RX
- Silicone tentacle molds (`22_moule_*`)

Priced rows above ≈ **1060 THB + servo + filament + CA / thermal pad**.

---

## Bambu Lab A1 print plan

Printer: **Bambu Lab A1**. Bed **256 × 256 × 256 mm**. Nozzle 0.4 mm.
A1 is **direct drive**, so TPU 95A at 30 mm/s is fine.

**There is no kit slicer profile.** Use Bambu Studio **Generic PETG** and
**Generic TPU**. Follow the table. Do not invent PLA.

### Print these five first — then stop

Magnet test: **01, 03, 04, 05, 07**. Glue magnets. Test through 3 mm
cardboard. Only then print the rest.

### Plates (suggested)

The A1 bed fits these groupings. Leave ~6 mm between parts.

| Plate | Files | Material | Notes |
|---|---|---|---|
| **1 — magnet test** | `01_capsule_upper.stl` · `03_stub_axle.stl` · `04_rotor_inner.stl` · `05_rotor_outer.stl` · `07_top_cap.stl` | PETG | Print, then **stop** for steps 1–4 |
| **2 — frame** | `08_stator.stl` · `09_slider_ring.stl` | PETG | Stator is 126 mm; ring is 113 mm. Side by side just fits |
| **3 — body + drive** | `02_fuselage.stl` · `06_cam_3lobe.stl` · `18_ballast_trellis.stl` · `20_tentacle_bar_PETG_x8.stl` ×8 | PETG | Fuselage stands 147 mm tall — under the 256 mm lid |
| **4 — float dome** | `13_float_dome.stl` | **Transparent PETG** | 160 mm across. One part per plate |
| **5 — float extras** | `13_float_disk.stl` · `13_float_plug.stl` | Transparent PETG | Disk is 145 mm. Do not put it on plate 4 |
| **6 — tentacles** | `optional/legacy_21_flanc_TPU_NOT_piece19.stl` ×**8** | **TPU 95A** | Each paddle is 22 × 209 mm (file 21). Eight in a row fit one A1 plate. 30 mm/s max |

Optional second TPU plate if the first warps or you want a spare.

### Orientation and settings (from the v6.2 notice)

| File | On the bed | Settings |
|---|---|---|
| 01 capsule | **Upside down**, top face on the bed | 40 % infill, 4 walls, **no support** |
| 02 fuselage | Collar on the bed, tail in the air | 4 walls, **no support** |
| 03 axle, 07 cap | Flat | **100 %** infill |
| 04 inner rotor | Magnet holes facing the bed | 50 % infill |
| 05 outer rotor, 06 cam | Upright, **large opening up** | 3–4 walls, **no support** |
| 08 stator | Upright | **Tree Slim** supports **under the ring only** |
| 09 sliding ring | Flat, bosses up | 3 walls |
| 19 TPU paddle (file 21) ×8 | Flat | TPU 95A, **30 mm/s max** |
| 20 tentacle bar ×8 | Flat, teton up | PETG, one plate |
| 13e / 13f / 13g | Skirt on bed / flat | Transparent PETG, **no support** |
| 18 ballast trellis | Bucket on the bed | 4 walls |

**Supports:** none, except the stator tree-slim under the ring. That is the
only support in this kit.

**Do not print** for a first swim: silicone molds, old clamp/rib/paddle
STLs, or `19_tentacle_skeleton_TPU_x8.stl` (a different reconstructed mesh).
The paddle you want is **`optional/legacy_21_flanc_TPU_NOT_piece19.stl`**
(original zip file 21). The barrette is **`20_tentacle_bar_PETG_x8.stl`**.

---

## Magnet test first

Print plate 1. Do **not** queue plates 2–6 yet.

1. Glue the six 8 × 3 mm magnets into **04** (step 1). Alternate N / S.
2. Screw 04 onto the servo horn (step 2).
3. Glue the six 8 × 3 mm magnets into **05** in the **opposite** pattern,
   plus two 5 × 2 mm Hall pips (step 3). Varnish the wet side.
4. Bolt axle **03** onto capsule **01** (step 4).

**Pass:** with ~3 mm of cardboard between 04 and 05, turning one rotor
turns the other. They snap into alignment. They must **attract**, not
repel.

**Fail:** one magnet is flipped. Soak, pop, re-glue. Fix this *before* you
spend PETG on the stator and cam.

How to find N and S: stack all twelve 8 × 3 mm magnets. They sort
themselves. Mark the top of the pile with a pen. Every marked face is the
same pole. Hole 1 = mark up. Hole 2 = mark down. Hole 3 = mark up. And so
on. For the outer rotor, **invert** that pattern.

---

## Cut eight films (do this while PETG prints)

File: `docs/GABARIT_FLANCS_1-1.pdf`

**Print that gabarit PDF on its own, at 100 % / actual size.** Do not
“fit to page.” Do **not** cut films from a thumbnail in this guide. The
outline is 212 mm long. A scaled print is waste.

1. Measure the **50.0 mm** control square on the paper. If it is not 50.0
   mm, reprint and fix the scale.
2. Tape or spray-mount the sheet on **0.3 mm PET**. One A4 holds two
   outlines → two films.
3. Cut the **solid** line with a cutter and a metal rule. Keep the 12 × 12
   mm teton at the root.
4. Before peeling, mark dashed **B1–B6** with a fine pen (placement guide
   along the TPU spine).
5. Repeat until you have **8 identical films**. Not 16.

Fold test: a film folded in half must spring back with **no white crease**.
A white crease means cheap PS, not PET. Buy again.

---

## Assembly 1–14

Have CA, silicone grease, PH1, and the varnished magnets ready.

### 1 — Inner rotor magnets (part 04)

Lay 04 flat, six round holes toward you. One CA drop per hole. Push each
8 × 3 mm magnet home so it is **flush**, not proud. Alternate N / S.

**Check:** a paperclip sticks to every magnet. Nothing sticks up.

A magnet glued the wrong way means the robot will not drive. Go slow.

### 2 — Screw 04 onto the servo

Clip the round servo horn onto the servo shaft. Set 04 on it, **magnets
up** (away from the servo). Four small screws through the rotor into the
horn. Spin by hand. It must run true.

**Check:** hold the rotor, turn the servo body. It must not unscrew.

### 3 — Outer rotor magnets (part 05)

Flip 05. The six magnet holes sit **under** the disk. Glue six 8 × 3 mm
magnets, **inverse** of 04. Glue both 5 × 2 mm magnets in the two small
edge pockets (Hall pips). Same way for both; polarity does not matter.

Test **before** the CA dies: hold 04 and 05 face to face with 3 mm
cardboard. They must attract and self-align.

**This rotor lives in water.** Varnish or thin-epoxy every magnet.

**Check:** turn one rotor; the other follows through the card. That is the
coupling through the capsule wall.

### 4 — Axle on the capsule (01 + 03)

Stand the capsule, top toward you. Three drilled bosses. Axle flange
matches. Three **M3 × 10**. Snug, do not strip. Silicone grease on the
whole axle stem and the flat thrust ring.

**Check:** the axle is vertical. It does not wiggle.

### 5 — Stator frame (08)

The stator **only goes on from the top**. It will not pass the fuselage
end. Slide until the split collar sits **10 mm below** the capsule
shoulder. Two **M3 × 16** in the collar ears. Cinch. The frame must not
rotate or slide by hand.

**Check:** three round columns are vertical. Three arms join the collar to
the columns (that is the v6 fix).

### 6 — Servo into the can

Lower the servo + inner rotor through the **bottom** opening, rotor **up**,
until it sits ~1 mm under the thin magnet roof.

CA the **NTC** onto the servo metal side. That side against the capsule
wall with a **thermal pad**. Foam on the other side. Heat leaves into the
water.

CA the **Hall** sensor flat under the roof, **28 mm from centre** (just
under the edge of the thin zone). Three wires drop to the ESP32. Servo
leads hang down for step 11.

**Check:** spin the outer rotor on top (not yet fitted). The inner rotor
follows through the wall.

### 7 — Outer rotor on the axle

Grease the centre hole of 05. Slide it on, **magnets down**. It will
*clack* onto the inner magnets. That is correct. Spin. It must ride the
thrust ring and **not** scrape the capsule.

**Check:** one finger turns it. You feel the inner rotor follow.

### 8 — Three-lobe cam + sliding ring

Look at the cam: three straight inner keys, a **wavy 3-lobe groove**
outside. Slide it onto the three tabs of the outer rotor, all the way
down.

Grease the wavy groove and the three stator columns.

Present the sliding ring **bosses up**: three holes on the three columns,
three pins pointing in. Lower it while turning the cam by hand so the
pins enter the groove.

Cap **07** on the axle. One **M3 × 8** in the centre.

Hard spot? A burr in the groove. Wrap 240-grit on a toothpick, then
re-grease.

**Check:** turning the cam by hand, the ring rises and falls **10 mm**,
stays flat, three times per turn, no force.

### 9 — Eight tentacles

Each tentacle = **1 TPU paddle (file 21)** + **1 PET film** + **1 PETG
barrette (20)**.

This paddle has a spine and a fishtail. It has **no Fin-Ray pads**. Do not
hunt for fourteen pads.

1. Lay the TPU paddle flat, teton up.
2. A **thin** CA line on the spine only. Not a flood.
3. Press the film on in one go, centred on the spine. B1–B6 are a
   placement guide. Palm for 10 seconds.
4. Glue the film’s 12 × 12 mm teton into the barrette **cuvette** (a blob
   of CA, 10 s).
5. Do all eight. No ribs to thread.

**Hang map (do not mix these up):**

- **Barrette teton → stator** (fixed ring, slots 8.6 × 3.0)
- **TPU teton → sliding ring**
- **Film teton → barrette cuvette**

**Check:** push the mid-span. It should curve toward your finger and
spring back. If it is a board, too much glue hit the spine. Peel the PET
with a cutter, clean, glue a thinner line.

### 10 — Hang tentacles on both rings

1. **Fixed ring** (top of the stator): barrette teton **from below** into
   each of the eight slots. A drop of CA. Films now hang from the frame.
2. Turn the cam until the sliding ring is **LOW**.
3. **Sliding ring:** TPU teton **from below** into its eight slots. A drop
   of CA (TPU holds better with it).
4. Order: eight barrettes first, ring low, then eight paddles.
5. No film rubbing a column while the CA sets.

A tentacle that beats out of time usually has its barrette and TPU swapped.

**Check:** turn the cam by hand. All eight curve **inward**, then release,
together. That is the pulse.

Root play of 2 mm eats half the stroke. Push tetons fully home.

### 11 — Wiring (leak on GPIO4)

The French notice said leak on **GPIO5**. That pin has **no ADC** on the
ESP32-C3. Kit firmware v6 reads leak on **GPIO4**. Wire it there.

```
18650  →  TP4056 B+ / B-  →  boost IN  →  boost 5 V OUT
                                              ├─ servo RED
                                              ├─ ESP32 5V pin
                                              └─ 470 µF  (long leg on +)

All blacks / browns together  =  GND

Servo yellow     →  GPIO10
Reed switch      →  GPIO3 and GND     (tap = run/stop or fault reset; 3 s = sleep)
NTC              →  GPIO0 and GND  +  10k from GPIO0 to 3.3 V
Battery divider  →  100k / 100k from pack + to GPIO1
Hall SS49E       →  3.3 V / GND / GPIO2
Leak probe       →  two bare wires at the lowest point of the capsule
                    +  470k from GPIO4 to 3.3 V     ★ GPIO4, not GPIO5
```

Set the boost to **5.0 V** (gold screw; a multimeter helps). Fixed-5 V
modules are fine.

Park the pack against the wall. CA the reed on the inner wall so you can
swipe the magnet from outside.

Leave `ENABLE_LED 0`. The LED ring would steal GPIO4 from the leak probe.

### 11b — Flash firmware

Board: **ESP32C3 Dev Module**. **USB CDC On Boot = Enabled**.

1. Install Arduino IDE from arduino.cc.
2. File → Preferences → Additional boards manager URLs:
   `https://espressif.github.io/arduino-esp32/package_esp32_index.json`
3. Boards Manager: **esp32 by Espressif Systems** (3.x is fine; the sketch
   also speaks 2.x LEDC).
4. Tools → Board → esp32 → **ESP32C3 Dev Module**.
5. Tools → **USB CDC On Boot = Enabled**.
6. USB-C data cable. Pick the port. If none: hold **BOOT** while plugging
   in, then release.
7. Open `firmware/firmware_medusa.ino` → Upload. Success looks like
   “Hash of data verified” / “Done uploading”. Failed to connect: BOOT
   trick again.

Leave flash size, frequency, partition, and upload speed on Arduino
defaults (typically 80 MHz, QIO, 4 MB, 921600). SuperMini is usually 4 MB.

No extra library for tank swim (`ENABLE_LED 0`).

### 11c — Phone remote

The jellyfish is its own Wi-Fi access point. Your phone browser is the
remote. No app. There is **no internet** on this network. That is normal.

SoftAP: **EXO-MEDUSA** / **medusa123** → **http://192.168.4.1**

**iPhone (Safari)**

1. Settings → Wi-Fi → join **EXO-MEDUSA**, password **medusa123**.
2. iOS may pop a “Log in” captive-portal page. That *is* the remote. Do
   not tap Cancel / Use without internet if you want the page to stay.
3. If nothing pops: Safari, type **http://192.168.4.1** (type it, do not
   Google it).
4. Toggle Wi-Fi if needed. Turn off VPN / iCloud Private Relay on this
   network.
5. Optional: Share → Add to Home Screen. Still just the browser.

**Android (Chrome)**

1. Join **EXO-MEDUSA**, password **medusa123**.
2. “Connected without internet” is correct. Stay. Disable auto-switch to
   mobile data if the phone hops away.
3. A “Sign in to network” banner may appear — open it. Else Chrome →
   **http://192.168.4.1**
4. If Chrome searches: type `http://` in front.

| Control | What it does |
|---|---|
| **SWIM** | Forward 55 % (remote; auto resumes after 120 s idle) |
| **STOP** | Speed 0 |
| **AUTO** | Built-in 8 s swim / 4 s glide at 42 % |
| **REV** | Reverse nudge (−35 %) |
| Slider | −100 % … +100 % |
| **RESET FAULT** | Clears a fault if the leak is gone |

Tiles (temp °C, battery V, RPM, mode, fault) poll `/status` every 1 s.

**BLE backup:** Android *Serial Bluetooth Terminal* (Bluetooth LE tab) or
iPhone *BLE Terminal*. Device `EXO-MEDUSA`. Text: `V50`, `V-40`, `S`,
`A`, `?`, `R`. Last order wins (Wi-Fi or BLE). The C3 is BLE only — it
will never appear in the phone’s headphone Bluetooth list.

If Wi-Fi + BLE together make the board flaky: `#define ENABLE_BLE 0` and
re-flash.

### 12 — O-ring and fuselage

Stretch the **53 × 3 mm** NBR O-ring into the groove at the end of the
fuselage plug. Grease it generously. Silicone grease *is* the seal.

Electronics go in through the fuselage opening: battery at the bottom,
boards along the wall.

Present fuselage under the capsule: three lugs facing three vertical
slots. Push home, then a sixth of a turn. Locked.

Never force it. Resistance = a wire on the joint.

**Check:** it does not unwind by itself. The shoulder sits flush.

### 13 — Float dome + ballast trellis

The dome is the **float**. Its chamber must be watertight (~195 cm³).

A continuous bead of **aquarium silicone (no fungicide)** on the inner
shoulder. Press disk **13f** on. Smooth with a finger. Silicone the apex
plug **13g** into the top hole. **Wait 24 hours.**

**Float test:** hold the dome alone underwater 10 minutes. **Zero
bubbles.** One bubble = redo that spot.

Sit the dome on the stator’s top ring. The lip self-centres. Three glue
dots.

Clip the ballast trellis onto the fuselage tail teton (three bosses in
the groove). About **40 g** of fishing sinkers in the bucket. Fine-tune
in step 14.

**Check:** the sealed dome floats hard on its own in a bucket. That is
what keeps the jelly head-up.

### 14 — Three tests before a tank

**Test 1 — dry pulse.** Power on. Stand the robot on a glass. All eight
tentacles must curl together about once a second (8 s swim / 4 s pause
at 42 % in AUTO).

**Test 2 — 24 h leak.** A paper towel **inside** the capsule. Close.
Weight it. Leave the capsule **24 h** at the bottom of a bucket of water.
The paper must come out **dry**. Wet paper = do not swim. Re-grease the
O-ring, twist it a quarter turn in its groove, repeat.

**Test 3 — tank trim.** Whole robot in water. Add or remove sinkers until
it sinks **very slowly**, upright, dome up. Swim will make up the rest.

Swipe the reed magnet to start/stop. Hold **3 seconds** for deep sleep.

Then film it. You earned that.

---

## Troubleshooting

**Stall / “Rotor bloque” / FAULT: rotor blocked**
The Hall no longer sees the outer rotor. Debris in the cam groove, a
follower pin jammed, or magnets too far. Firmware tries three reverse
kicks, then faults. Clean the groove. Turn by hand. **RESET FAULT** on
the phone page, or a magnet tap on the reed. If it still slips: re-glue
outer magnets 0.3 mm proud.

**Leak fault / “FUITE — ouvrir et secher la capsule”**
GPIO4 saw a wet analog reading (threshold &lt; 1200). Open. Dry. Find the
path (O-ring, bayonet, a wire in the groove). Re-grease. 24 h paper-towel
test again. RESET FAULT only after the leak is gone. Confirm the 470k
pull-up is on **GPIO4**, not GPIO5.

**Won’t join Wi-Fi / no page**
Stay on **EXO-MEDUSA**. There is no internet — phones love to hop away.
Disable “auto switch to mobile data.” Type **http://192.168.4.1**, do not
search. iPhone: use the captive-portal page; skip VPN / Private Relay.
If the SSID never appears: ESP32 has no 5 V, empty 18650, or a charge-only
USB cable during flash. TP4056 LED should show charge/idle.

**Servo twitch, will not turn = missing 470 µF**
The servo brown-outs on the 5 V rail. Fit **470 µF 10 V** across servo
5 V, long leg on +. Feed that rail from the **boost**, never through the
ESP32. Weak pack or a boost under 2 A looks the same. Set 5.0 V.

**Pulses but does not go forward**
Too heavy or too light — redo trim. Reverse the speed on the phone page.
Check tentacles curl **inward** on the down-stroke.

**One tentacle out of time**
Film unstuck, or barrette and TPU swapped on that station.

**Floats tilted or inverts**
Dome chamber leaking (bucket test: zero bubbles) or not enough tail
ballast. Watertight dome up + lead down = upright.

**Hard spot on the sliding ring**
Burr in the cam groove or on a column. 240-grit, then silicone grease.
Check the three pins are intact.

**Water in the capsule**
O-ring dry, pinched, or a print scar in the groove. Re-grease, quarter-turn
the ring, 24 h test.

**No port in Arduino IDE**
Hold **BOOT** while plugging USB, then release. Use a **data** USB-C
cable.

**Invisible on Bluetooth**
Normal in the headphone list. Use a BLE terminal app. If still nothing:
`ENABLE_BLE 1`.

**“Pause thermique” / overheat FAULT**
Firmware protects the servo: derate 52 °C, pause 58 °C, fault 65 °C.
Check the thermal pad to the wall. Let AUTO glide. Do not swim 100 %
in a hot room.

---

## What this kit is not

No steering. No depth sensor. No LED dome (leave `ENABLE_LED 0` so leak
can stay on GPIO4). No Qi lid. No Festo two-plate cam. Build the second
jelly after this one swims.

---

## First swim checklist

Tick these before the jelly goes in the tank.

1. **Print** — Magnet-test plate 01/03/04/05/07 passed through 3 mm card. Outer magnets varnished.
2. **Print** — Rest of PETG, transparent dome, TPU paddles ×8 (file 21), barrettes ×8. Stator is the only part with Tree Slim supports.
3. **Film** — `GABARIT_FLANCS_1-1.pdf` printed at 100 %. Control square is 50.0 mm. Eight films, tetons intact.
4. **Tentacles** — Barrette teton → stator. TPU teton → sliding ring. Film teton → barrette cuvette. Cam-by-hand pulse inward.
5. **Wiring** — Leak on GPIO4 (not GPIO5). Servo red from the boost. 470 µF across 5 V, long leg on +.
6. **Flash** — `firmware_medusa.ino` on ESP32C3 Dev Module. USB CDC On Boot = Enabled. AUTO 8 s / 4 s.
7. **Phone** — Wi-Fi EXO-MEDUSA / medusa123 → http://192.168.4.1. SWIM / STOP / AUTO work.
8. **Dry pulse** — On a glass, eight tentacles curl together. No stall fault. No twitch (if twitch: missing 470 µF).
9. **Dome** — Silicone, no fungicide. 24 h cure. 10 min underwater, zero bubbles.
10. **Capsule** — Paper towel inside. 24 h at the bottom of a bucket. Paper comes out dry.
11. **Trim** — Sinks very slowly, dome up, ~40 g in the tail bucket. Then swim.
12. **Kids / pets** — N52 magnets boxed. 18650 in its holder. CA capped.

---

*EXO-MEDUSA consumer kit v6 · Bambu Lab A1 · tank-swim*

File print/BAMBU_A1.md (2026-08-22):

# Bambu Lab A1 — slicer settings (EXO-MEDUSA)

Printer: **Bambu Lab A1 · 0.4 mm nozzle · 256 × 256 × 256 mm**
Plate: **Textured PEI** unless noted. Glue stick as a *release agent* for PETG (it sticks too well) and for TPU 95A.

These numbers are taken from **Bambu Studio system presets** on GitHub (`resources/profiles/BBL/`, master, 2026) plus the assembly notice. Where the notice is stricter than the profile, the notice wins and is marked.

## How to set this up in Bambu Studio

1. Printer: **Bambu Lab A1 0.4 nozzle**
2. Process: **0.20mm Standard @BBL A1** (change layer height only where the table says 0.16 mm)
3. Filament:
   - Structure: **Generic PETG @BBL A1**
   - Dome: **Bambu PETG Translucent @BBL A1** (or Generic PETG @BBL A1 + the translucent overrides below)
   - Skeletons: **Generic TPU @BBL A1**, feed from the **external spool holder** (not AMS Lite)
4. Load `print/EXO-MEDUSA_A1.3mf` *or* the STLs in `print/stl/`. Follow `plates.md` — do **not** print everything in one job.

Process **0.20mm Standard @BBL A1** inherits `fdm_process_single_0.20`: outer wall 200 mm/s, inner 300, infill 270, first layer 50, travel 700 mm/s, acceleration 6000 mm/s², elephant-foot 0.075 mm. **Volumetric caps below will slow PETG/TPU well under those wall speeds.** That is expected.

---

## Filament A — Generic PETG @BBL A1 (structure)

**Official A1 preset** (`Generic PETG @BBL A1.json` → `Generic PETG @base` → `fdm_filament_pet`):

| Setting | Official value | Notes |
|---|---|---|
| Nozzle | **255 °C** (range 220–260) | `fdm_filament_pet.nozzle_temperature` |
| Nozzle first layer | **255 °C** | same |
| Textured PEI bed | **80 °C** (first layer 80 °C) | A1 override; base generic is 70 °C |
| Flow ratio | **0.95** | Bambu PETG family; do not raise if it clogs |
| Max volumetric | **8 mm³/s** | A1 override (base generic is 12) |
| Density | **1.27 g/cm³** | mass estimates below |
| Fan min / max | 40 % / 90 % | `@base` |
| Line width (0.4 nozzle) | outer 0.42 / inner 0.45 | wiki default |

**Notice overrides (apply these on top):**

- Supports: **off**, except stator **Tree Slim** under the upper ring only.
- Walls / infill: per-part table, not the profile default of 2 walls.
- Glue stick on textured PEI so PETG releases without ripping the sheet.
- Dry PETG 60–65 °C / 8 h before a long plate (wiki).

Effective extrusion speed at 0.20 × 0.42 mm and 8 mm³/s ≈ **95 mm/s**, so the 200 mm/s outer-wall process number will not be reached. Leave the volumetric cap at 8.

## Filament B — Bambu PETG Translucent @BBL A1 (dome 13)

**Official A1 preset** (`Bambu PETG Translucent @BBL A1.json` → `@base`):

| Setting | Official value |
|---|---|
| Nozzle | **245 °C** (first layer **250 °C**, range 230–270) |
| Textured PEI bed | **70 °C** |
| Flow ratio | **0.95** |
| Max volumetric | **6 mm³/s** |
| Density | **1.25 g/cm³** |
| Fan min / max | **10 % / 30 %** |
| Retraction | **0.3 mm** (A1 file) |

**Dome-specific (wiki “increase transparency” + watertight float):**

- **Extra outer walls:** 5–6 (kit table uses 6). Strength and fewer leak paths beat crystal-clear.
- **Ironing:** optional on the disk top face only (helps the silicone seal). Off on the dome.
- Slow outer wall if you want clearer parts: wiki says **20 mm/s** and fan off for show-piece transparency. For a working float, stay on the official 6 mm³/s cap (~70 mm/s) with low fan.
- No supports. Skirt / brim 5 mm if the Ø160 skirt lifts.
- Same textured PEI + glue stick.

## Filament C — Generic TPU @BBL A1 (skeletons ×8)

**Official A1 preset** (`Generic TPU @BBL A1.json` → `Generic TPU @base` → `fdm_filament_tpu`):

| Setting | Official value | Kit / notice |
|---|---|---|
| Nozzle | **240 °C** (range 200–250) | keep |
| Textured PEI bed | **45 °C** (A1 override; TPU base is 35 °C) | keep |
| Max volumetric | **3.2 mm³/s** (`Generic TPU @base`) | **notice is stricter** |
| Density | **1.24 g/cm³** | mass estimates |
| Retraction | **0.4 mm** | A1 direct drive; do not raise |
| Fan | min **100 %** | keep |
| SuperTack / Cool plate | **0 °C = incompatible** | use textured PEI |

**Notice + A1 TPU practice (these win):**

- **30 mm/s max** — outer, inner, infill. Slow the outer wall further if corners fuzz. (30 mm/s × 0.20 × 0.42 ≈ 2.5 mm³/s, under the 3.2 cap.)
- **Glue stick** on textured PEI.
- **External spool**, short PTFE path. AMS Lite is not for 95A.
- Disable flow-dynamics / pressure-advance calibration if the A1 complains on TPU.
- First layer 20–25 mm/s. Z-hop 0.2–0.4 mm if it snags pads.
- Dry 50–70 °C / 5–8 h.

Wiki hardware note: TPU 95A is compatible with the A1 0.4 mm nozzle; TPU 85A is not.

---

## Per-part table

Mass and time are **estimates from STL mesh volume × fill factor × official volumetric cap**, plus ~30 % travel overhead. They are not Bambu Studio slice previews. Use them to plan overnight jobs.

| File | Material | Qty | Layer | Infill | Walls | Supports | Orientation | BBox mm (X×Y×Z) | Mass g/ea | Time /ea | Fits 256? |
|---|---|---|---|---|---|---|---|---|---|---|---|
| `01_capsule_upper.stl` | PETG | 1 | 0.20 | 40% | 4 | none | upside-down, roof / magnet face on bed | 66.0×66.0×66.0 | 37.7 | ~1 h 20 min | YES |
| `02_fuselage.stl` | PETG | 1 | 0.20 | 40% | 4 | none | bayonet collar on bed, tail up | 66.0×66.0×147.0 | 44.5 | ~1 h 34 min | YES |
| `03_stub_axle.stl` | PETG | 1 | 0.20 | 100% | 4 | none | flat, axis vertical | 26.0×26.0×48.5 | 8.8 | ~18 min | YES |
| `04_rotor_inner.stl` | PETG | 1 | 0.20 | 50% | 4 | none | magnet pockets toward the bed | 54.0×54.0×12.0 | 7.5 | ~15 min | YES |
| `05_rotor_outer.stl` | PETG | 1 | 0.20 | 25% | 4 | none | standing, large opening up | 64.0×65.5×48.0 | 54.4 | ~1 h 55 min | YES |
| `06_cam_3lobe.stl` | PETG | 1 | 0.20 | 25% | 4 | none | standing, bore vertical (opening up) | 78.0×78.0×40.0 | 40.0 | ~1 h 25 min | YES |
| `07_top_cap.stl` | PETG | 1 | 0.20 | 100% | 3 | none | flat | 30.0×30.0×3.0 | 2.7 | ~5 min | YES |
| `08_stator.stl` | PETG | 1 | 0.20 | 30% | 4 | tree slim under upper ring only | standing (collar down, ring up) | 126.0×126.0×99.0 | 49.9 | ~1 h 34 min | YES |
| `09_slider_ring.stl` | PETG | 1 | 0.20 | 20% | 3 | none | flat, bosses UP | 112.6×110.0×14.0 | 21.1 | ~44 min | YES |
| `13_float_dome.stl` | Transparent PETG | 1 | 0.16 | 15% | 6 | none | skirt on bed, apex up | 160.0×160.0×53.0 | 81.5 | ~3 h 55 min | YES |
| `13_float_disk.stl` | Transparent PETG | 1 | 0.20 | 20% | 6 | none | flat | 145.0×145.0×3.0 | 52.6 | ~2 h 32 min | YES |
| `13_float_plug.stl` | Transparent PETG | 1 | 0.20 | 100% | 4 | none | flat | 30.0×30.0×6.0 | 3.8 | ~10 min | YES |
| `18_ballast_trellis.stl` | PETG | 1 | 0.20 | 40% | 4 | none | bucket / godet on bed | 33.0×33.0×60.0 | 6.8 | ~14 min | YES |
| `19_tentacle_skeleton_TPU_x8.stl` | TPU 95A | 8 | 0.20 | 20% | 3 | none | flat, pads + teton UP | 30.0×154.0×9.4 | 3.3 | ~23 min | YES |
| `20_tentacle_bar_PETG_x8.stl` | PETG | 8 | 0.20 | 100% | 3 | none | flat, body on bed, teton UP | 18.0×20.0×7.7 | 1.4 | ~3 min | YES |

**Totals (all qty, estimated):** PETG **285 g / ~9 h 54 min** · Transparent PETG **138 g / ~6 h 38 min** · TPU 95A **27 g / ~3 h 04 min**.

Buy a **1 kg PETG** spool, a **small transparent PETG** spool, and **≥ 100 g TPU 95A**. Brim, purge, and a failed magnet-test eat the rest.

## Print order (matches the notice)

1. **First job — magnet-test only:** `01`, `03`, `04`, `05`, `07`. Stop and glue magnets (notice étapes 1–4). Rotors must clap together through ~3 mm card. Then print the rest.
2. Structure PETG (plate 2).
3. TPU ×8 (plate 3) — one skeleton, gabarit overlay, then the other seven if B1–B6 land on the bars.
4. Transparent dome (plate 4), then disk + plug (plate 5).

## A1 256 × 256 packing (computed from STL bounding boxes)

See `plates.md` for coordinates. Summary:

| Plate | Footprints | Fit? |
|---|---|---|
| 1 magnet-test | 66, 26, 54, 66, 30 mm | **yes**, one plate with margin |
| 2 structure | stator **126×126** + slider **113×110** + cam 78 + fuselage 66 + trellis 33 + eight 18×20 bars | **yes**, one plate, tight but ≤ 251 mm |
| 3 TPU ×8 | eight **30×154** | **yes** as one row (8×30 + gaps ≈ 247 mm). Two rows of 4 need 316 mm — **does not fit**. Optional split: two plates of 4. |
| 4 dome | **160×160** | **yes**, alone |
| 5 disk + plug | **145×145** + 30×30 | **yes** together. **Dome + disk = 160+145 > 256 — cannot share a plate.** |

**No default part is larger than the A1 bed.** Tallest Z is the fuselage at **147 mm** (collar-down). Stator standing is 99 mm.

## Starting-point label

If Bambu Studio on your computer has different profile numbers (filament lot / Studio version), **trust the named system preset** (`Generic PETG @BBL A1`, `Generic TPU @BBL A1`, `Bambu PETG Translucent @BBL A1`) over this file, then re-apply the notice overrides (30 mm/s TPU, Tree Slim on the stator only, extra walls on the dome).

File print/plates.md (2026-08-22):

# Plate packing — Bambu Lab A1 (256 × 256 mm)

Origin is the front-left of the textured PEI, millimetres, part **bounding-box min-corner**.
Leave ≥ 4 mm to the bed edge. Coordinates assume each STL is dropped with **Z-min on the bed** (Bambu “Lay on Face” / auto-orient as in the table). Rotate in the slicer to match **Orientation** before trusting XY.

Usable pack window used here: **4–252 mm**.

## Plate 1 — MAGNET TEST (print this first, then stop)

Filament: **Generic PETG @BBL A1**. Process: 0.20 mm Standard. No supports.

| Part | Qty | Footprint | Place min-corner (X, Y) | Occupies to |
|---|---|---|---|---|
| 01_capsule_upper | 1 | 66 × 66 | (8, 8) | (74, 74) |
| 05_rotor_outer | 1 | 64 × 66 | (82, 8) | (148, 74) |
| 04_rotor_inner | 1 | 54 × 54 | (156, 8) | (210, 62) |
| 03_stub_axle | 1 | 26 × 26 | (8, 82) | (34, 108) |
| 07_top_cap | 1 | 30 × 30 | (42, 82) | (72, 112) |

All five sit in the front ~210 × 112 mm. Spare bed is unused on purpose — this job is the go/no-go for magnets.

After the plate: notice étapes 1–4. If the rotors do not attract through ~3 mm of plastic, **do not start plate 2**.

## Plate 2 — STRUCTURE (PETG)

Filament: **Generic PETG @BBL A1**. Stator: enable **Tree Slim** supports, upper ring only. Everyone else: supports off.

| Part | Qty | Footprint | Place min-corner (X, Y) | Occupies to |
|---|---|---|---|---|
| 08_stator | 1 | 126 × 126 | (4, 4) | (130, 130) |
| 09_slider_ring | 1 | 113 × 110 | (138, 4) | (251, 114) |
| 06_cam_3lobe | 1 | 78 × 78 | (138, 122) | (216, 200) |
| 02_fuselage | 1 | 66 × 66 | (4, 138) | (70, 204) |
| 18_ballast_trellis | 1 | 33 × 33 | (78, 138) | (111, 171) |
| 20_tentacle_bar_PETG ×8 | 8 | 18 × 20 each | see grid below | leftover bay |

Barrette grid in the leftover bay **(138, 208) – (252, 252)** — 4 × 2, 4 mm gaps, teton up:

```
(138, 208) (160, 208) (182, 208) (204, 208)
(138, 232) (160, 232) (182, 232) (204, 232)
```

Fuselage Z is **147 mm** with the collar on the bed — under the 256 mm cap. Stator standing is 99 mm.

If you prefer a safer first-layer, split: plate 2a = 08+06+18, plate 2b = 02+09+20×8. Not required.

## Plate 3 — TPU ×8

Filament: **Generic TPU @BBL A1**, external spool, **30 mm/s**, glue stick.

Each skeleton is **30 × 154 × 9.4 mm**. Eight in one row along X, long axis along Y:

| Copy | min-corner (X, Y) | Occupies to |
|---|---|---|
| 1 | (6, 51) | (36, 205) |
| 2 | (37, 51) | (67, 205) |
| 3 | (68, 51) | (98, 205) |
| 4 | (99, 51) | (129, 205) |
| 5 | (130, 51) | (160, 205) |
| 6 | (161, 51) | (191, 205) |
| 7 | (192, 51) | (222, 205) |
| 8 | (223, 51) | (253, 205) |

Gaps are **1 mm**. This is the tightest plate in the kit. If first-layer adhesion looks nervous, **split into two plates of 4** (copies 1–4 and 5–8) with 8 mm gaps — notice allows “1–2 plates”.

**Do not** try two rows of 4 with the 154 mm side along Y: 154+154+gap = 316 mm > 256.

Print **one** skeleton on a scrap corner first, overlay `docs/GABARIT_FLANCS_1-1.pdf` (50.0 mm square), then run the ×8 plate.

## Plate 4 — TRANSPARENT DOME

Filament: **Bambu PETG Translucent @BBL A1** (or Generic PETG + translucent overrides). 6 walls. No supports. Skirt on bed.

| Part | Footprint | Place |
|---|---|---|
| 13_float_dome | **160 × 160** | centred (48, 48) → (208, 208) |

The dome **cannot** share a plate with the Ø145 disk (160 + 145 + gap > 256).

## Plate 5 — TRANSPARENT DISK + PLUG

Same filament as plate 4.

| Part | Footprint | Place min-corner | Occupies to |
|---|---|---|---|
| 13_float_disk | 145 × 145 | (8, 8) | (153, 153) |
| 13_float_plug | 30 × 30 | (161, 8) | (191, 38) |

## What does **not** fit

| Combination | Why |
|---|---|
| Dome 13 + disk 13 on one plate | 160 + 145 mm > 256 |
| TPU skeletons as 2×4 with long axis along Y | 154 × 2 > 256 |
| Any single default part vs 256 mm | **none** — every default STL is inside 256 × 256 × 256 |

Optional clamp/rib/paddle (old tentacle path) are tiny and would fit on any leftover PETG plate. They are **not** on the default plates.

## 3MF

`print/EXO-MEDUSA_A1.3mf` already places objects with these XY translations (Z-min baked to the bed). Open it in Bambu Studio, assign filaments per plate, and slice **one plate at a time** starting with plate 1.

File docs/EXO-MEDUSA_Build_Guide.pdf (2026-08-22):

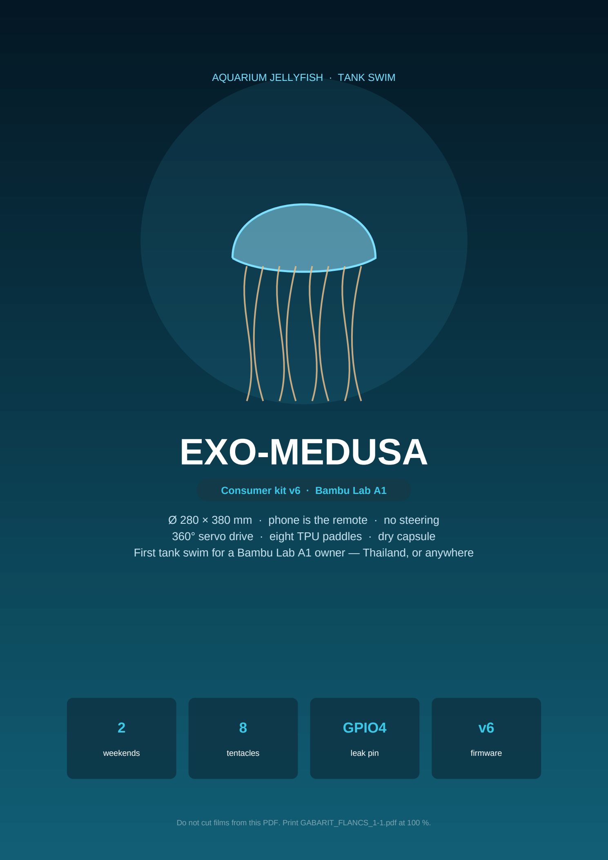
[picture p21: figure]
AQUARIUM JELLYFISH · TANK SWIM; EXO-MEDUSA; Consumer kit v6 · Bambu Lab A1; weekends; tentacles; GPIO4; leak pin; firmware

Ø 280 × 380 mm · phone is the remote · no steering
360° servo drive · eight TPU paddles · dry capsule
First tank swim for a Bambu Lab A1 owner — Thailand, or anywhere

Do not cut films from this PDF. Print GABARIT_FLANCS_1-1.pdf at 100 %.

EXO-MEDUSA | Consumer kit v6 · Bambu Lab A1

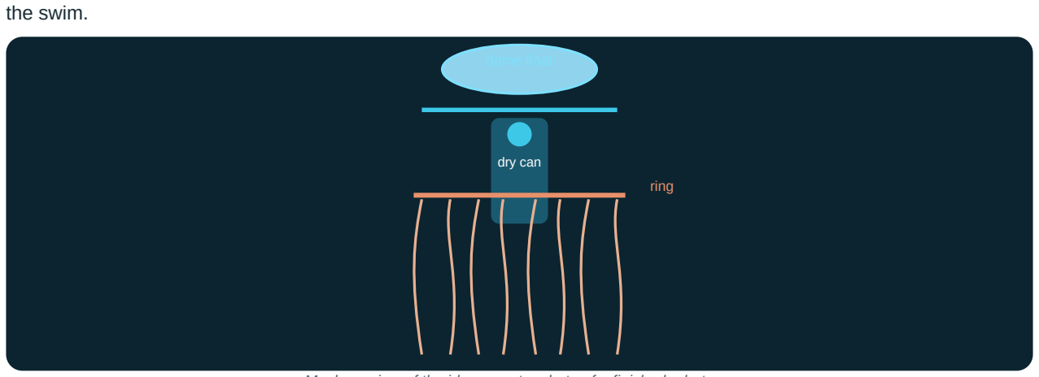
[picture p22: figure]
the swim.; dome float; ring; dry can

Tank-swim · no steering · leak on GPIO4 | page 2

## What you are building

You are building EXO-MEDUSA: an aquarium jellyfish about Ø 280 × 380 mm. A dry electronics capsule sits in the middle. A 360° servo turns magnets inside the can. Matching magnets outside follow through the wall. A 3-lobe cam then pumps a sliding ring 10 mm, three times per turn. The ring bends eight tentacles inward together. That pulse is

Mesh preview of the idea — not a photo of a finished robot.

- Your phone browser is the remote. No app to install.
- There is no steering. It pulses and drifts. That is this kit.
- No electrical part lives in the water. Servo, battery and ESP32 stay dry.
- Firmware is v6. Leak sense is on GPIO4 (not GPIO5 from the old French notice).
- Drive is a 360° continuous servo: DS04-NFC or MG996R 360. Not a Furitek.

Tentacles in this kit
Print the TPU paddle eight times (original zip file 21, 22 × 209 mm). Kit path: print/stl/optional/legacy_21_flanc_TPU_NOT_piece19.stl. It is a paddle, not the missing Fin-Ray ladder. It still fits the 8.6 × 3.0 mm slots. Print 20_tentacle_bar_PETG_x8.stl eight times (alias 20_barrette_PETG_x8.stl). Cut eight films from GABARIT_FLANCS_1-1.pdf at 100 % scale. Skip 19_tentacle_skeleton_TPU_x8.stl for these steps — different mesh.

Budget two weekends. One PH1 screwdriver. Super glue. A Bambu Lab A1. Thailand shop list uses Lazada / Shopee search terms. The same parts exist anywhere.

## Safety — read this first

N52 magnets can kill if swallowed
They pinch hard and chip if they slam together. Keep them away from children. A swallowed N52 magnet is lethal. Two magnets (or one magnet and metal) can trap bowel. This is not a toy drawer.

18650 shorts
Never short the + and − tabs. Never puncture. Charge only through the TP4056 module. No bare-cell chargers. No loose cells in a pocket with keys.

CA glue
Cyanoacrylate bonds skin in about five seconds. Ventilate. Keep it off eyes. Have acetone or a CA debonder nearby.

Servo 5 V does not go through the ESP32
The servo red wire goes to the boost 5 V output. The ESP32 may share that rail. Do not feed servo current through the chip. A 470 µF capacitor sits across servo 5 V (long leg on +). Missing that cap is why a servo twitches and will not turn.

Aquarium silicone — no fungicide
100 % clear aquarium silicone. No fungicide. No anti-mould. Bathroom silicone can kill fish and is the wrong tube.

Also. Never force the bayonet lid — a wire is on the O-ring. Coat every wet-side magnet (outer rotor) with nail varnish or thin epoxy. Nickel plating is not enough in water. If the float dome leaks, the robot inverts. The dome is the float, not decoration.

## What you need

Buy on Lazada / Shopee Thailand, or anywhere. Prices are ballpark THB from the kit shop list, except the servo (the old spreadsheet had the wrong motor).

### Electronics

What | Qty | Search | ~THB
360° servo DS04-NFC or MG996R 360 | 1 | DS04-NFC 360 / MG996R 360 continuous | —
ESP32-C3 SuperMini | 1 | ESP32-C3 SuperMini | 105
18650 + holder (3000 mAh) | 1 | 18650 battery holder | 140
TP4056 with protection (DW01) | 1 | TP4056 protection | 35
5 V boost ≥ 2 A (MT3608) | 1 | MT3608 boost 5V | 35
470 µF 10 V electrolytic | 1 | 470uF electrolytic | 17.5
SS49E linear Hall | 1 | SS49E hall sensor | 17.5
NTC 10k B3950 | 1 | NTC 10k 3950 | 17.5
Reed switch + small magnet | 1 | reed switch glass | 35
Resistors 10k×1, 100k×2, 470k×1 | 1 kit | resistor kit | 35

### Mechanics, film, glue

What | Qty | Search | ~THB
N52 magnets 8 × 3 mm | 12 | N52 8x3 magnet | 105
N52 magnets 5 × 2 mm | 2 | N52 5x2 magnet | 35
NBR O-ring ~53 × 3 mm | 1 | o-ring 53x3 | 35
Silicone grease (plumbing, not auto) | 1 | silicone grease plumbing | 70
PET film 0.3 mm A4 | 10 sh. | PET sheet 0.3mm A4 | 70
M3: 16 mm×2, 10 mm×3, 8 mm×5 | 1 kit | M3 screw kit | 70
Fishing sinkers ~40 g | 1 | fishing sinkers split shot | 70
Aquarium silicone 100% clear, no fungicide | 1–2 | aquarium silicone sealant clear 100% | 175
5-minute epoxy | 1 | epoxy glue 5 minutes | 70
CA glue + thermal pad + foam + nail varnish | 1 | super glue CA / thermal pad servo | —

### Filament for the A1

Filament | ~mass | Use
PETG | ~450 g | capsule, stator, cam, ring, axle, rotors, barrettes
Transparent PETG | ~95 g | float dome 13e / disk 13f / plug 13g
TPU 95A | ~60 g | tentacle paddles ×8 (legacy_21_flanc… file 21)

Do not buy for this first swim
Furitek Mini-Komodo (wrong drive). WS2812 LED ring. SG90 pendulum. Qi wireless TX/RX. Silicone tentacle molds 22_moule_*. Priced rows above ≈ 1060 THB + servo + filament + CA / pad.

Tools. PH1 screwdriver. Cutter + metal rule. Basic soldering iron. USB-C data cable (charge-only cables will not flash). Optional: multimeter for the 5.0 V set.

## Bambu Lab A1 print plan

Printer: Bambu Lab A1. Bed 256 × 256 × 256 mm. Nozzle 0.4 mm. A1 is direct drive, so TPU 95A at 30 mm/s is fine. There is no kit slicer profile. Use Bambu Studio Generic PETG and Generic TPU. Do not invent PLA.

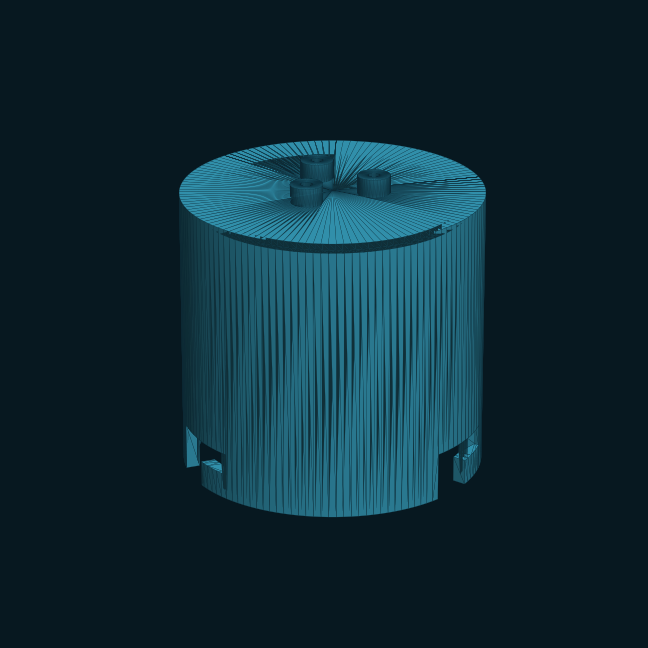
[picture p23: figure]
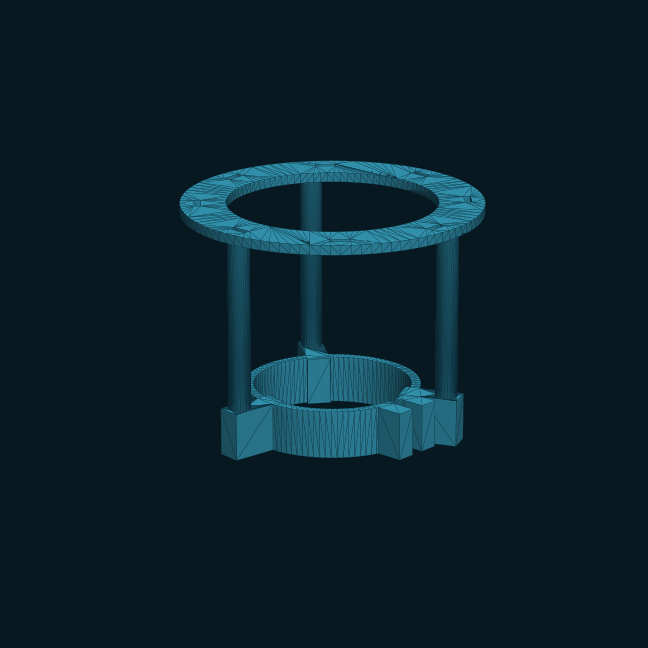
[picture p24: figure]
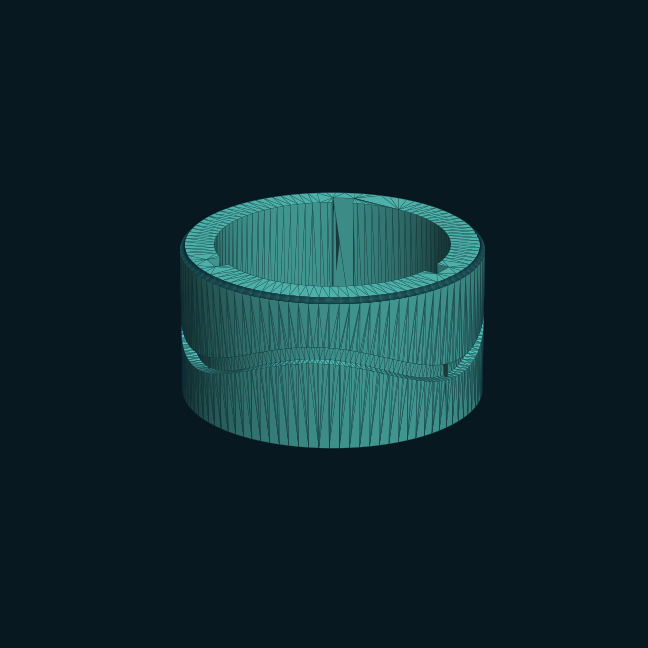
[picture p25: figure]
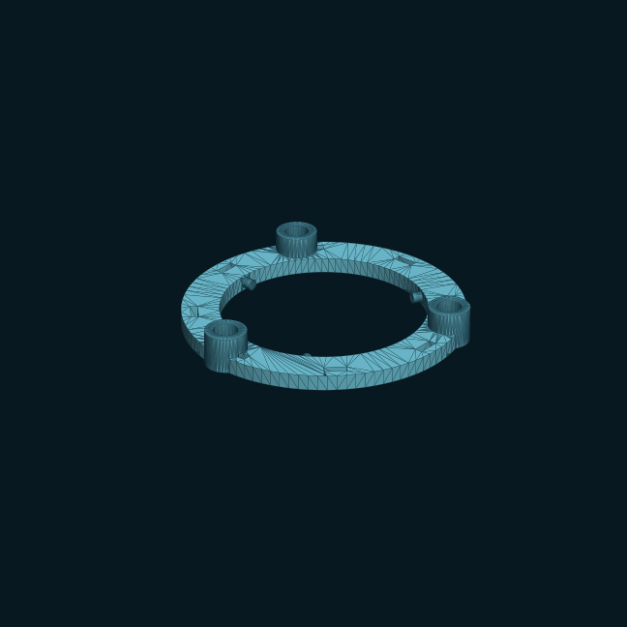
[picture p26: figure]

01 capsule | 08 stator | 06 3-lobe cam | 09 sliding ring

STL previews from the kit meshes. Identify parts. These are not photos.

Magnet-test parts first — then stop
Print 01, 03, 04, 05, 07 only. Glue magnets. Test through 3 mm cardboard. Then print the rest. Do not queue the whole job overnight.

### Suggested plates

Plate | Files | Material | Notes
1 magnet test | 01_capsule_upper · 03_stub_axle · 04_rotor_inner · 05_rotor_outer · 07_top_cap | PETG | Print, then STOP
2 frame | 08_stator · 09_slider_ring | PETG | 126 mm + 113 mm just fit
3 body + drive | 02_fuselage · 06_cam_3lobe · 18_ballast_trellis · 20_tentacle_bar ×8 | PETG | Fuselage is 147 mm tall
4 float dome | 13_float_dome | Transparent PETG | 160 mm — one part
5 float extras | 13_float_disk · 13_float_plug | Transparent PETG | Disk is 145 mm
6 tentacles | legacy_21_flanc (file 21) ×8 | TPU 95A | 22×209 mm. 30 mm/s max

### Orientation and settings (v6.2 notice)

File | On the bed | Settings
01 capsule | Upside down, top face on the bed | 40 % infill, 4 walls, no support
02 fuselage | Collar on the bed, tail in the air | 4 walls, no support
03 axle, 07 cap | Flat | 100 % infill
04 inner rotor | Magnet holes facing the bed | 50 % infill
05 outer rotor, 06 cam | Upright, large opening up | 3–4 walls, no support
08 stator | Upright | Tree Slim supports under the ring only
09 sliding ring | Flat, bosses up | 3 walls
19 TPU paddle (file 21) ×8 | Flat | TPU 95A, 30 mm/s max
20 tentacle bar ×8 | Flat, teton up | PETG, one plate
13e / 13f / 13g | Skirt on bed / flat | Transparent PETG, no support
18 ballast trellis | Bucket on the bed | 4 walls

Supports: none, except the stator tree-slim under the ring. That is the only support in this kit. Do not print silicone molds or old clamp/rib/paddle STLs. The paddle you want is optional/legacy_21_flanc_TPU_NOT_piece19.stl (file 21). Skip 19_tentacle_skeleton_TPU_x8.stl for this first swim — different mesh.

## Magnet test first


04 inner rotor | 05 outer rotor | 01 capsule
Print plate 1. Do not queue plates 2–6 yet. Glue six 8×3 mm magnets into 04 (step 1), alternate N/S. Screw 04 onto the servo horn (step 2). Glue six 8×3 mm magnets into 05 in the opposite pattern, plus two 5×2 mm Hall pips (step 3). Varnish the wet side. Bolt axle 03 onto capsule 01 (step 4).

Polarity cheat

Stack 12 magnets. Mark the top of the pile. That mark is one pole.
Inner 04: mark-up, mark-down, mark-up, mark-down, mark-up, mark-down Outer 05: invert that pattern so the two rotors ATTRACT through the wall. Hall 5×2 pips: same way both. Polarity does not matter.
N | S | N | S | N | S

inner 04

Pass / fail
Pass: with ~3 mm of cardboard between 04 and 05, turning one rotor turns the other. They snap into alignment. They must attract, not repel. Fail: one magnet is flipped. Soak, pop, re-glue. Fix this before you spend PETG on the stator and cam.

## Cut eight films

Print the gabarit PDF at 100 % — do not cut from this guide
Open docs/GABARIT_FLANCS_1-1.pdf and print it on its own at 100 % / actual size. Do not “fit to page.” The outline is 212 mm long. A scaled-down thumbnail in a build guide is waste. Do not cut films from any picture on these pages.
1. Measure the 50.0 mm control square on the gabarit paper. If it is not
50.0 mm, reprint.
2. Tape or spray-mount the sheet on 0.3 mm PET. One A4 = two outlines = two films.
3. Cut the solid line with a cutter and a metal rule. Keep the 12×12 mm teton at the root.
4. Before peeling, mark dashed B1–B6 with a fine pen (placement guide along the TPU spine).
5. Repeat until you have 8 identical films. Not 16. (The old notice title said 16; the body text and gabarit say eight.)
Fold test: a film folded in half must spring back with no white crease. A white crease is cheap PS, not PET.

### 50.0 mm

Control square (print the GABARIT at 100%)

## Assembly 1–7

Have CA, silicone grease, PH1, and the varnished magnets ready. Short sentences. Check each box.

### 1 Inner rotor magnets · part 04

- Lay 04 flat, six round holes toward you.
- One CA drop per hole. Push each 8×3 mm magnet home so it is flush, not proud.
- Alternate N / S. A magnet glued the wrong way means the robot will not drive.

Check. A paperclip sticks to every magnet. Nothing sticks up.

### 2 Screw 04 onto the servo

- Clip the round servo horn onto the servo shaft.
- Set 04 on it, magnets up (away from the servo).
- Four small screws through the rotor into the horn. Spin by hand. It must run true.

Check. Hold the rotor, turn the servo body. It must not unscrew.

### 3 Outer rotor magnets · part 05 · this side lives in water

- Flip 05. The six magnet holes sit under the disk.
- Glue six 8×3 mm magnets, inverse of 04.
- Glue both 5×2 mm magnets in the two small edge pockets (Hall pips). Same way for both.
- Test before the CA dies: 04 and 05 face to face with 3 mm cardboard. They must attract and self-align.
- Varnish or thin-epoxy every magnet on this rotor. Nickel plating corrodes in water.

Check. Turn one rotor; the other follows through the card.

### 4 Axle on the capsule · 01 + 03

- Stand the capsule, top toward you. Three drilled bosses.
- Axle flange matches. Three M3 × 10. Snug, do not strip.
- Silicone grease on the whole axle stem and the flat thrust ring.

Check. The axle is vertical. It does not wiggle.

### 5 Stator frame · part 08

- The stator only goes on from the top. It will not pass the fuselage end.
- Slide until the split collar sits 10 mm below the capsule shoulder.
- Two M3 × 16 in the collar ears. Cinch. The frame must not rotate or slide by hand.

Check. Three round columns are vertical. Three arms join the collar to the columns (the v6 fix).

### 6 Servo into the can

- Lower the servo + inner rotor through the bottom opening, rotor up, until ~1 mm under the thin magnet roof.
- CA the NTC onto the servo metal side. That side against the capsule wall with a thermal pad. Foam on the other side. Heat leaves into the water.
- CA the Hall sensor flat under the roof, 28 mm from centre (just under the edge of the thin zone). Three wires drop to the ESP32.
- Servo leads hang down for step 11.

Check. Spin the outer rotor on top (not yet fitted). The inner rotor follows through the wall.

### 7 Outer rotor on the axle

- Grease the centre hole of 05. Slide it on, magnets down.
- It will clack onto the inner magnets. That is correct.
- Spin. It must ride the thrust ring and not scrape the capsule.

Check. One finger turns it. You feel the inner rotor follow.

06 cam — wavy groove outside | 09 ring — pins ride the groove | 08 stator — three columns

### 8 Three-lobe cam + sliding ring

- Look at the cam: three straight inner keys, a wavy 3-lobe groove outside. Slide it onto the three tabs of the outer rotor, all the way down.
- Grease the wavy groove and the three stator columns.
- Present the sliding ring bosses up: three holes on the three columns, three pins pointing in.
- Lower it while turning the cam by hand so the pins enter the groove.
- Cap 07 on the axle. One M3 × 8 in the centre.
- Hard spot? A burr in the groove. Wrap 240-grit on a toothpick, then re-grease.

Check. Turning the cam by hand, the ring rises and falls 10 mm, stays flat, three times per turn, no force.

## Tentacles · steps 9–10


TPU paddle · file 21 · print ×8 | 20 PETG barrette · print ×8

Hang map — do not mix these up
Barrette teton → stator (fixed ring, slots 8.6 × 3.0). TPU teton → sliding ring. Film teton → barrette cuvette.

### 9 Glue eight tentacles on the table

Each tentacle = 1 TPU paddle (19) + 1 PET film + 1 PETG barrette (20). This paddle has a spine and a fishtail. It has no Fin-Ray pads. Do not hunt for fourteen pads.

- Lay the TPU paddle flat, teton up.
- A thin CA line on the spine only. Not a flood.
- Press the film on in one go, centred on the spine. B1–B6 are a placement guide. Palm for 10 seconds.
- Glue the film’s 12 × 12 mm teton into the barrette cuvette (a blob of CA, 10 s).
- Do all eight. No ribs to thread.

Check. Push the mid-span. It should curve toward your finger and spring back. If it is a board, too much glue hit the spine. Peel the PET with a cutter, clean, glue a thinner line.

### 10 Hang tentacles on both rings

- Fixed ring (top of the stator): barrette teton from below into each of the eight slots. A drop of CA. Films now hang from the frame.
- Turn the cam until the sliding ring is LOW.
- Sliding ring: TPU teton from below into its eight slots. A drop of CA (TPU holds better with it).
- Order: eight barrettes first, ring low, then eight paddles.
- No film rubbing a column while the CA sets.
- A tentacle that beats out of time usually has its barrette and TPU swapped.

Check. Turn the cam by hand. All eight curve inward, then release, together. That is the pulse. Root play of 2 mm eats half the stroke. Push tetons fully home.

## Wiring · step 11 · leak on GPIO4

GPIO4, not GPIO5
The French notice said leak on GPIO5. That pin has no ADC on the ESP32-C3. Kit firmware v6 reads leak on GPIO4. Two bare wires at the lowest point of the capsule, plus 470k from GPIO4 to 3.3 V. Analog wet threshold < 1200. Leave ENABLE_LED 0 — a WS2812 ring would steal GPIO4.

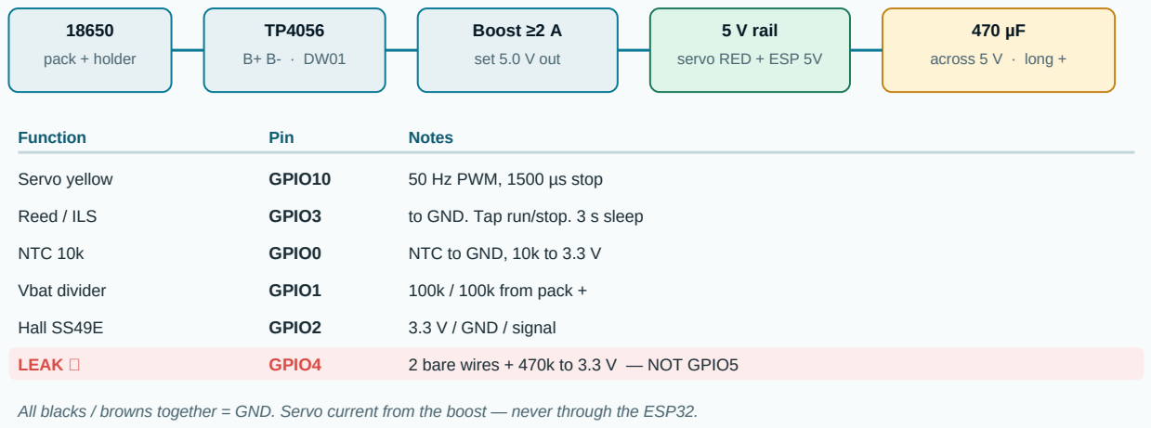
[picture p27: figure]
pack + holder; Boost ≥2 A; set 5.0 V out; 5 V rail; servo RED + ESP 5V; across 5 V · long +; Function; Pin; Notes; NTC 10k; GPIO0; NTC to GND, 10k to 3.3 V; Hall SS49E; GPIO2; 3.3 V / GND / signal

Servo yellow | GPIO10 | 50 Hz PWM, 1500 µs stop
Reed / ILS | GPIO3 | to GND. Tap run/stop. 3 s sleep
Vbat divider | GPIO1 | 100k / 100k from pack +
LEAK | GPIO4 | 2 bare wires + 470k to 3.3 V — NOT GPIO5

All blacks / browns together = GND. Servo current from the boost — never through the ESP32.

- Solder pack +/− to TP4056 B+ / B−. TP4056 OUT to boost IN. Set boost to 5.0 V.
- Boost 5 V out → servo red and ESP32 5V pin. All blacks together.
- 470 µF across that 5 V rail, long leg on +.
- Park the pack against the wall. CA the reed on the inner wall so you can swipe the magnet from outside.

Check after flash. Servo runs 8 s then pauses 4 s (AUTO at 42 %). Phone sees Wi-Fi EXO-MEDUSA / password medusa123. Page http://192.168.4.1.

### Flash firmware · step 11b

Board: ESP32C3 Dev Module. Tools → USB CDC On Boot = Enabled. File: firmware/firmware_medusa.ino.

- Install Arduino IDE from arduino.cc.
- File → Preferences → Additional boards manager URLs: https://espressif.github.io/arduino-esp32/package_esp32_index.json
- Boards Manager: esp32 by Espressif Systems (3.x is fine; the sketch also speaks 2.x LEDC).
- Tools → Board → esp32 → ESP32C3 Dev Module. USB CDC On Boot = Enabled.
- USB-C data cable. Pick the port. If none: hold BOOT while plugging in, then release.
- Open the sketch → Upload. Success looks like “Hash of data verified” / “Done uploading”. Failed to connect: BOOT trick again.

Leave flash size, frequency, partition and upload speed on Arduino defaults (typically 80 MHz, QIO, 4 MB, 921600). SuperMini is usually 4 MB. No extra library for tank swim.

## Phone remote · step 11c

The jellyfish is its own Wi-Fi access point. Your phone browser is the remote. No app. There is no internet on this network. That is normal. Stay on it.

SoftAP
EXO-MEDUSA / medusa123 → http://192.168.4.1

### iPhone (Safari)

- Settings → Wi-Fi → join EXO-MEDUSA, password medusa123.
- iOS may pop a “Log in” captive-portal page. That is the remote. Do not tap Cancel / Use without internet if you want the page to stay.
- If nothing pops: Safari, type http://192.168.4.1 (type it, do not Google it).
- Toggle Wi-Fi if needed. Turn off VPN / iCloud Private Relay on this network.
- Optional: Share → Add to Home Screen. Still just the browser.

### Android (Chrome)

- Join EXO-MEDUSA, password medusa123.
- “Connected without internet” is correct. Stay. Disable auto-switch to mobile data if the phone hops away.
- A “Sign in to network” banner may appear — open it. Else Chrome → http://192.168.4.1.
- If Chrome searches: type http:// in front of the address.

### Controls

Control | What it does
SWIM | Forward 55 % (remote; auto resumes after 120 s idle)
STOP | Speed 0
AUTO | Built-in 8 s swim / 4 s glide at 42 %
REV | Reverse nudge (−35 %)
Slider | −100 % … +100 %
RESET FAULT | Clears a fault if the leak is gone

Tiles (temp °C, battery V, RPM, mode, fault) poll /status every 1 s. BLE backup: Android Serial Bluetooth Terminal (Bluetooth LE tab) or iPhone BLE Terminal. Device EXO-MEDUSA. Text: V50, V-40, S, A, ?, R. Last order wins. The C3 is BLE only — it will never appear in the headphone Bluetooth list. If Wi-Fi + BLE together make the board flaky: #define ENABLE_BLE 0 and re-flash.

## Seal, float, tests · steps 12–14


02 fuselage · O-ring in the plug groove | 13e float dome · transparent PETG

### 12 O-ring and fuselage

- Stretch the 53 × 3 mm NBR O-ring into the groove at the end of the fuselage plug.
- Grease it generously. Silicone grease is the seal.
- Electronics go in through the fuselage opening: battery at the bottom, boards along the wall.
- Present fuselage under the capsule: three lugs facing three vertical slots. Push home, then a sixth of a turn. Locked.
- Never force it. Resistance = a wire on the joint.

Check. It does not unwind by itself. The shoulder sits flush.

### 13 Float dome + ballast trellis

- The dome is the float. Its chamber must be watertight (~195 cm³).
- A continuous bead of aquarium silicone (no fungicide) on the inner shoulder. Press disk 13f on. Smooth with a finger.
- Silicone the apex plug 13g into the top hole. Wait 24 hours.
- Float test: hold the dome alone underwater 10 minutes. Zero bubbles. One bubble = redo that spot.
- Sit the dome on the stator’s top ring. The lip self-centres. Three glue dots.
- Clip the ballast trellis onto the fuselage tail teton. About 40 g of fishing sinkers in the bucket. Fine-tune in step 14.

Check. The sealed dome floats hard on its own in a bucket. That keeps the jelly head-up.

### 14 Three tests before a tank

Test 1 — first dry pulse. Power on. Stand the robot on a glass. All eight tentacles must curl together about once a second (8 s swim / 4 s pause at 42 % in AUTO).

Test 2 — 24 h leak. A paper towel inside the capsule. Close. Weight it. Leave the capsule 24 h at the bottom of a bucket of water. The paper must come out dry. Wet paper = do not swim. Re-grease the O-ring, twist it a quarter turn in its groove, repeat.

Test 3 — tank trim. Whole robot in water. Add or remove sinkers until it sinks very slowly, upright, dome up. Swim will make up the rest.

Swipe the reed magnet to start/stop. Hold 3 seconds for deep sleep. Then film it. You earned that.

## Troubleshooting

### Stall / “Rotor bloque” / FAULT: rotor blocked

The Hall no longer sees the outer rotor. Debris in the cam groove, a follower pin jammed, or magnets too far. Firmware tries three reverse kicks, then faults. Clean the groove. Turn by hand. RESET FAULT on the phone page, or a magnet tap on the reed. If it still slips: re-glue outer magnets 0.3 mm proud.

### Leak fault / “FUITE — ouvrir et secher la capsule”

GPIO4 saw a wet analog reading (threshold < 1200). Open. Dry. Find the path (O-ring, bayonet, a wire in the groove). Re-grease. 24 h paper-towel test again. RESET FAULT only after the leak is gone. Confirm the 470k pull-up is on GPIO4, not GPIO5.

### Won’t join Wi-Fi / no page

Stay on EXO-MEDUSA. There is no internet — phones love to hop away. Disable “auto switch to mobile data.” Type http://192.168.4.1, do not search. iPhone: use the captive-portal page; skip VPN / Private Relay. If the SSID never appears: ESP32 has no 5 V, empty 18650, or a charge-only USB cable during flash. TP4056 LED should show charge/idle.

### Servo twitch, will not turn = missing 470 µF

The servo brown-outs on the 5 V rail. Fit 470 µF 10 V across servo 5 V, long leg on +. Feed that rail from the boost, never through the ESP32. A weak pack or a boost under 2 A looks the same. Set 5.0 V.

### Pulses but does not go forward

Too heavy or too light — redo trim. Reverse the speed on the phone page. Check tentacles curl inward on the down-stroke.

### One tentacle out of time

Film unstuck, or barrette and TPU swapped on that station.

### Floats tilted or inverts

Dome chamber leaking (bucket test: zero bubbles) or not enough tail ballast. Watertight dome up + lead down = upright.

### Hard spot on the sliding ring

Burr in the cam groove or on a column. 240-grit, then silicone grease. Check the three pins are intact.

### Water in the capsule

O-ring dry, pinched, or a print scar in the groove. Re-grease, quarter-turn the ring, 24 h test.

### No port in Arduino IDE

Hold BOOT while plugging USB, then release. Use a data USB-C cable.

### Invisible on Bluetooth

Normal in the headphone list. Use a BLE terminal app. If still nothing: ENABLE_BLE 1.

### “Pause thermique” / overheat FAULT

Firmware protects the servo: derate 52 °C, pause 58 °C, fault 65 °C. Check the thermal pad to the wall. Let AUTO glide. Do not swim 100 % in a hot room.

What this kit is not
No steering. No depth sensor. No LED dome (leave ENABLE_LED 0 so leak can stay on GPIO4). No Qi lid. No Festo two-plate cam. Build the second jelly after this one swims.

## First swim checklist

Tick these before the jelly goes in the tank. Short list. No surprises in the water.
□

### 1. Print

Magnet-test plate 01/03/04/05/07 passed through 3 mm card. Outer magnets varnished.
□

### 2. Print

Rest of PETG, transparent dome, TPU paddles ×8 (file 21), barrettes ×8. Stator is the only part with Tree Slim supports.
□

### 3. Film

GABARIT_FLANCS_1-1.pdf printed at 100 %. Control square is 50.0 mm. Eight films, tetons intact.
□

### 4. Tentacles

Barrette teton → stator. TPU teton → sliding ring. Film teton → barrette cuvette. Cam-by-hand pulse inward.
□

### 5. Wiring

Leak on GPIO4 (not GPIO5). Servo red from the boost. 470 µF across 5 V, long leg on +.
□

### 6. Flash

firmware_medusa.ino on ESP32C3 Dev Module. USB CDC On Boot = Enabled. AUTO 8 s / 4 s.
□

### 7. Phone

Wi-Fi EXO-MEDUSA / medusa123 → http://192.168.4.1. SWIM / STOP / AUTO work.
□

### 8. Dry pulse

On a glass, eight tentacles curl together. No stall fault. No twitch (if twitch: missing 470 µF).
□

### 9. Dome

Silicone, no fungicide. 24 h cure. 10 min underwater, zero bubbles.
□

### 10. Capsule

Paper towel inside. 24 h at the bottom of a bucket. Paper comes out dry.
□

### 11. Trim

Sinks very slowly, dome up, ~40 g in the tail bucket. Then swim.
□

### 12. Kids / pets

N52 magnets boxed. 18650 in its holder. CA capped.

EXO-MEDUSA consumer kit v6 · Bambu Lab A1 · tank-swim

STLs and firmware were not changed to make this guide.

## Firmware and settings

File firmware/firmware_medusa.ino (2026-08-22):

/* EXO-MEDUSA v6 kit - ESP32-C3 SuperMini - FAILPROOF + phone WiFi remote + BLE backup
 * tank-swim: LED off, leak on GPIO4, LEDC 2.x/3.x
 * Phone remote is the AP page (http://192.168.4.1). BLE still works as backup.
 *
 * PILOTAGE (les deux marchent en meme temps, le dernier ordre gagne) :
 *  WiFi : reseau "EXO-MEDUSA", mdp "medusa123", page http://192.168.4.1  (telephone = telecommande)
 *  Bluetooth : BLE (Nordic UART). App gratuite "Serial Bluetooth Terminal"
 *    (Android, onglet Bluetooth LE) ou "BLE Terminal" (iPhone).
 *    Commandes texte : V50 = vitesse 50% | V-40 = arriere | S = stop
 *                      A = cycle auto | ? = etat (temperature, batterie, tr/min)
 *  HONNETE : l'ESP32-C3 fait du Bluetooth Low Energy UNIQUEMENT (pas de
 *  Bluetooth "classique") : il n'apparait PAS dans les appareils audio du
 *  telephone, seulement dans les apps BLE. C'est normal.
 *  Si WiFi+BLE ensemble sont instables sur ta carte : mets ENABLE_BLE a 0.
 *
 * BROCHAGE : servo GPIO10 | ILS GPIO3 | NTC GPIO0 | Vbat GPIO1 | Hall GPIO2 | fuite GPIO4
 * SECURITES : patinage (Hall), thermique (52/58/65 C), batterie 3,35 V,
 *             fuite, watchdog 8 s, condo 470 uF. Voir notice etape 11.
 */
#define ENABLE_WIFI 1
#define ENABLE_BLE  1
#define ENABLE_LED  0     // anneau WS2812 8 LEDs sous la fenetre : dome lumineux facon Festo
                          // (installer la bibliotheque "Adafruit NeoPixel" dans le gestionnaire)
                          // si ENABLE_LED 1 : deplacer PIN_LEAK hors de GPIO4 (conflit anneau)

#include <esp_task_wdt.h>
#if ENABLE_LED
#include <Adafruit_NeoPixel.h>
Adafruit_NeoPixel led(8, 4, NEO_GRB + NEO_KHZ800);   // GPIO4, 8 LEDs — fuite doit alors quitter GPIO4
void ledStatus(int mode_, bool swimming, float phase){
  uint32_t c;
  if (mode_==2)      c = led.Color(120,0,0);                       // FAUTE : rouge
  else if (mode_==1) c = led.Color(90,45,0);                       // pause thermique : orange
  else if (swimming){ int b = 30+90*(0.5f-0.5f*cosf(phase));       // nage : respiration bleue
                      c = led.Color(0, b/3, b); }
  else               c = led.Color(18,18,22);                      // glisse : blanc doux
  for (int i=0;i<8;i++) led.setPixelColor(i,c);
  led.show();
}
#endif
#include <math.h>
#if ENABLE_WIFI
#include <WiFi.h>
#include <WebServer.h>
#endif
#if ENABLE_BLE
#include <BLEDevice.h>
#include <BLEServer.h>
#include <BLE2902.h>
#endif

const int PIN_SERVO=10, PIN_REED=3, PIN_NTC=0, PIN_VBAT=1, PIN_HALL=2, PIN_LEAK=4;
const int CH=0, US_STOP=1500, TRIM=0;
const uint32_t SWIM_MS=8000, GLIDE_MS=4000; const int SWIM_SPEED=42;   // ~0.6-0.7 Hz : marge de couple x1.3-1.8 validee (voir SYSTEM_DESIGN)
const float T_SOFT=52.0, T_PAUSE=58.0, T_FAULT=65.0, T_RESUME=50.0, V_LOW=3.35;
const int HALL_DELTA=140; const uint32_t STALL_WIN=2500;

// Arduino-ESP32 3.x : LEDC par broche (ledcAttach / ledcWrite(pin, duty)).
// 2.x : LEDC par canal (ledcSetup / ledcAttachPin / ledcWrite(ch, duty)).
#if defined(ESP_ARDUINO_VERSION_MAJOR) && (ESP_ARDUINO_VERSION_MAJOR >= 3)
#define LEDC_V3 1
#else
#define LEDC_V3 0
#endif

enum Mode { RUN, PAUSED_HOT, FAULT_MODE };
Mode mode=RUN; String faultCause="";
int speedPct=0, cmdNow=0; bool running=true, remote=false;
uint32_t lastCmd=0, reedDown=0, lastPulse=0, stallRetries=0, lastRpmCalc=0;
int hallBase=0; bool hallHigh=false; volatile uint32_t pulseCount=0;
float tServo=25, vBat=4.0, rpm=0;

void writeServo(int pct){ pct=constrain(pct,-100,100);
  uint32_t duty=(uint32_t)(US_STOP+TRIM+pct*5)*65536/20000;  // 50 Hz, 16 bit : ±100% → ±500 us
#if LEDC_V3
  ledcWrite(PIN_SERVO, duty);
#else
  ledcWrite(CH, duty);
#endif
}
float readTemp(){ int a=analogRead(PIN_NTC);
  float r=10000.0*a/(4095.0-a+1);
  return 1.0/(1.0/298.15+log(r/10000.0)/3950.0)-273.15; }
float readVbat(){ return analogRead(PIN_VBAT)*3.3*2.0/4095.0; }
bool leak(){ return analogRead(PIN_LEAK)<1200; }
void fault(String w){ mode=FAULT_MODE; faultCause=w; writeServo(0); }
String statusTxt(){ String s="T:"+String(tServo,1)+"C V:"+String(vBat,2)+" R:"+String(rpm,1)+"tr/min";
  if(mode==FAULT_MODE) s+=" FAUTE:"+faultCause;
  if(mode==PAUSED_HOT) s+=" PAUSE-CHAUD"; return s; }

void handleCmd(String c){                       // commun WiFi + BLE
  c.trim(); c.toUpperCase();
  if(c.startsWith("V")){ speedPct=c.substring(1).toInt(); remote=true; lastCmd=millis(); }
  else if(c=="S"){ speedPct=0; remote=true; lastCmd=millis(); }
  else if(c=="A"){ remote=false; }
  else if(c=="R"){ if(mode==FAULT_MODE && !leak()){ mode=RUN; stallRetries=0; faultCause=""; } }
}

#if ENABLE_WIFI
WebServer srv(80);
const char PAGE[] PROGMEM = R"html(<!DOCTYPE html>
<html lang="en">
<head>
<meta charset="utf-8">
<meta name="viewport" content="width=device-width,initial-scale=1,maximum-scale=1,user-scalable=no,viewport-fit=cover">
<meta name="apple-mobile-web-app-capable" content="yes">
<meta name="mobile-web-app-capable" content="yes">
<meta name="apple-mobile-web-app-status-bar-style" content="black-translucent">
<meta name="theme-color" content="#041018">
<title>EXO-MEDUSA</title>
<style>
*{box-sizing:border-box;-webkit-tap-highlight-color:transparent}
html,body{margin:0;min-height:100%;color:#d4eefc;
font-family:-apple-system,BlinkMacSystemFont,Segoe UI,sans-serif;text-align:center}
body{background:#030b12 radial-gradient(ellipse at 50% -10%,#0c4a6e 0%,#082032 38%,#030b12 70%);
padding:calc(14px + env(safe-area-inset-top)) 16px calc(24px + env(safe-area-inset-bottom))}
.bell{width:72px;height:48px;margin:4px auto 2px;border-radius:36px 36px 8px 8px;
background:radial-gradient(circle at 50% 30%,#7ec8ff 0%,#1a6a9a 45%,transparent 70%);opacity:.85}
h1{margin:0;font-size:1.28rem;letter-spacing:.22em;font-weight:650;color:#bfe9ff;text-shadow:0 0 18px #3aa8e0}
.tag{margin:.25rem 0 12px;font-size:.68rem;letter-spacing:.28em;text-transform:uppercase;opacity:.55}
.hint{background:rgba(10,40,64,.7);border:1px solid #1a4e72;border-radius:14px;padding:10px 12px;margin:0 0 14px;
font-size:.78rem;line-height:1.45;color:#9ccce8}
.hint b{color:#e8f6ff}
.live{display:inline-block;width:8px;height:8px;border-radius:50%;background:#3d6a80;margin-right:6px;vertical-align:middle}
.live.on{background:#5ee0a0;box-shadow:0 0 8px #5ee0a0}
.grid{display:grid;grid-template-columns:1fr 1fr;gap:8px;margin:0 0 12px}
.tile{background:rgba(8,28,44,.85);border:1px solid #16425e;border-radius:14px;padding:12px 8px;min-height:64px}
.tile b{display:block;font-size:1.28rem;color:#eef8ff;font-variant-numeric:tabular-nums}
.tile span{font-size:.62rem;letter-spacing:.14em;text-transform:uppercase;opacity:.5}
.fault{display:none;background:#3a1218;color:#ff9a9a;border:1px solid #8a3038;border-radius:14px;
padding:12px 14px;margin:0 0 12px;font-size:.9rem;min-height:44px;line-height:1.35}
.row{display:flex;gap:8px;margin:8px 0}
button{flex:1;min-height:52px;border:0;border-radius:16px;font-size:1.02rem;font-weight:700;letter-spacing:.08em;
color:#eef8ff;background:#14344c;cursor:pointer;touch-action:manipulation}
button.go{background:linear-gradient(180deg,#1c88b0,#0d5a78);min-height:64px;font-size:1.25rem}
button.stop{background:linear-gradient(180deg,#b04050,#6a1828);min-height:64px;font-size:1.25rem}
button.auto{background:linear-gradient(180deg,#1a5a82,#0e3048)}
button.rev{background:linear-gradient(180deg,#2a4a6a,#163040)}
button.quiet{background:#0e2436;color:#8eb4cc;font-weight:600;letter-spacing:.04em}
button:active{transform:scale(.97);filter:brightness(1.1)}
.sl{margin:10px 4px 0}
input[type=range]{-webkit-appearance:none;appearance:none;width:90%;height:44px;background:transparent;margin:0}
input[type=range]::-webkit-slider-runnable-track{height:8px;background:#15344c;border-radius:8px}
input[type=range]::-webkit-slider-thumb{-webkit-appearance:none;width:28px;height:28px;margin-top:-10px;
border-radius:50%;background:#8ad4ff;box-shadow:0 0 12px #4ab4e8}
.spd{margin:0 0 8px;font-size:1.05rem}
.ok{color:#7ee0b0}.warn{color:#ffcc66}.bad{color:#ff8a8a}
.foot{margin-top:16px;font-size:.68rem;opacity:.4;line-height:1.4}
</style>
</head>
<body>
<div class="bell"></div>
<h1>EXO-MEDUSA</h1>
<div class="tag">v6 kit · phone remote</div>
<div class="hint"><span class="live" id="dot"></span>Connect to Wi-Fi <b>EXO-MEDUSA</b>, password <b>medusa123</b>, then open <b>http://192.168.4.1</b></div>
<div class="fault" id="fault"></div>
<div class="grid">
<div class="tile"><b id="t">—</b><span>temp °C</span></div>
<div class="tile"><b id="v">—</b><span>battery V</span></div>
<div class="tile"><b id="rpm">—</b><span>rpm</span></div>
<div class="tile"><b id="mode">—</b><span>mode</span></div>
</div>
<div class="row">
<button type="button" class="go" id="bSwim">SWIM</button>
<button type="button" class="stop" id="bStop">STOP</button>
</div>
<div class="row">
<button type="button" class="auto" id="bAuto">AUTO</button>
<button type="button" class="rev" id="bRev">REV</button>
</div>
<div class="sl"><input id="sl" type="range" min="-100" max="100" value="0"></div>
<div class="spd">speed <b id="sv">0</b>%</div>
<div class="row"><button type="button" class="quiet" id="bRst">RESET FAULT</button></div>
<div class="foot">BLE still works as backup · last command wins</div>
<script>
function $(i){return document.getElementById(i)}
function cmd(x){fetch('/c?x='+encodeURIComponent(x))}
var drag=0;
$('bSwim').onclick=function(){cmd('V55');$('sl').value=55;$('sv').textContent=55};
$('bStop').onclick=function(){cmd('S');$('sl').value=0;$('sv').textContent=0};
$('bAuto').onclick=function(){cmd('A')};
$('bRev').onclick=function(){cmd('V-35');$('sl').value=-35;$('sv').textContent=-35};
$('bRst').onclick=function(){cmd('R')};
$('sl').oninput=function(){drag=1;$('sv').textContent=this.value};
function setV(){cmd('V'+$('sl').value);drag=0}
$('sl').onchange=setV;
$('sl').addEventListener('touchend',setV);
function poll(){
fetch('/status').then(function(r){return r.json()}).then(function(j){
$('dot').className='live on';
$('t').textContent=Number(j.t).toFixed(1);
$('v').textContent=Number(j.v).toFixed(2);
$('rpm').textContent=Number(j.rpm).toFixed(1);
$('mode').textContent=j.mode+(j.remote?' · remote':' · auto')+(j.running?'':' · off');
$('mode').className=j.mode=='FAULT'?'bad':(j.mode=='PAUSED_HOT'?'warn':'ok');
if(j.fault){$('fault').style.display='block';$('fault').textContent=j.fault}
else $('fault').style.display='none';
if(!drag){$('sl').value=j.cmd;$('sv').textContent=j.cmd}
}).catch(function(){$('dot').className='live'});
}
setInterval(poll,1000);poll();
</script>
</body>
</html>)html";

String jsonStatus(){
  const char* m="RUN";
  if(mode==PAUSED_HOT) m="PAUSED_HOT";
  else if(mode==FAULT_MODE) m="FAULT";
  String f=faultCause;
  f.replace("\\","\\\\"); f.replace("\"","\\\"");
  String s; s.reserve(192);
  s+="{\"t\":"; s+=String(tServo,1);
  s+=",\"v\":"; s+=String(vBat,2);
  s+=",\"rpm\":"; s+=String(rpm,1);
  s+=",\"mode\":\""; s+=m;
  s+="\",\"fault\":\""; s+=f;
  s+="\",\"running\":"; s+=(running?"true":"false");
  s+=",\"remote\":"; s+=(remote?"true":"false");
  s+=",\"cmd\":"; s+=cmdNow;
  s+='}';
  return s;
}
void sendPage(){ srv.send_P(200,"text/html",PAGE); }
#endif

#if ENABLE_BLE
BLECharacteristic *bleTx=nullptr; bool bleUp=false;
class SrvCB: public BLEServerCallbacks {
  void onConnect(BLEServer*){ bleUp=true; }
  void onDisconnect(BLEServer* s){ bleUp=false; s->getAdvertising()->start(); } };
class RxCB: public BLECharacteristicCallbacks {
  void onWrite(BLECharacteristic* ch){
    String v=String(ch->getValue().c_str());
    handleCmd(v);
    if(v=="?" && bleTx){ bleTx->setValue(statusTxt().c_str()); bleTx->notify(); } } };
#endif

void setup(){
  pinMode(PIN_REED,INPUT_PULLUP); pinMode(PIN_LEAK,INPUT);
  analogReadResolution(12);
#if LEDC_V3
  ledcAttach(PIN_SERVO, 50, 16);
#else
  ledcSetup(CH, 50, 16); ledcAttachPin(PIN_SERVO, CH);
#endif
  writeServo(0);
  hallBase=analogRead(PIN_HALL);
#if ENABLE_LED
  led.begin(); led.show();
#endif
  esp_task_wdt_config_t w={.timeout_ms=8000,.idle_core_mask=0,.trigger_panic=true};
  esp_task_wdt_init(&w); esp_task_wdt_add(NULL);

#if ENABLE_WIFI
  WiFi.softAP("EXO-MEDUSA","medusa123");
  srv.on("/", sendPage);
  srv.on("/hotspot-detect.html", sendPage);
  srv.on("/generate_204", sendPage);
  srv.on("/c",[](){ handleCmd(srv.arg("x")); srv.send(200,"text/plain","ok"); });
  srv.on("/status",[](){ srv.send(200,"application/json",jsonStatus()); });
  srv.onNotFound(sendPage);
  srv.begin();
#endif
#if ENABLE_BLE
  BLEDevice::init("EXO-MEDUSA");
  BLEServer* bs=BLEDevice::createServer(); bs->setCallbacks(new SrvCB());
  BLEService* svc=bs->createService("6E400001-B5A3-F393-E0A9-E50E24DCCA9E");
  bleTx=svc->createCharacteristic("6E400003-B5A3-F393-E0A9-E50E24DCCA9E",
        BLECharacteristic::PROPERTY_NOTIFY);
  bleTx->addDescriptor(new BLE2902());
  BLECharacteristic* rx=svc->createCharacteristic("6E400002-B5A3-F393-E0A9-E50E24DCCA9E",
        BLECharacteristic::PROPERTY_WRITE|BLECharacteristic::PROPERTY_WRITE_NR);
  rx->setCallbacks(new RxCB());
  svc->start(); bs->getAdvertising()->addServiceUUID(svc->getUUID());
  bs->getAdvertising()->start();
#endif
  lastPulse=millis();
}

void pollHall(){
  int d=abs(analogRead(PIN_HALL)-hallBase);
  if(d>HALL_DELTA && !hallHigh){ hallHigh=true; pulseCount++; lastPulse=millis(); }
  else if(d<HALL_DELTA/2) hallHigh=false;
}

void loop(){
  esp_task_wdt_reset();
#if ENABLE_WIFI
  srv.handleClient();
#endif
  pollHall();

  static uint32_t tMeas=0;
  if(millis()-tMeas>500){ tMeas=millis();
    tServo=0.7*tServo+0.3*readTemp(); vBat=0.8*vBat+0.2*readVbat();
    uint32_t dt=millis()-lastRpmCalc;
    if(dt>3000){ rpm=pulseCount*60000.0/(2.0*dt); pulseCount=0; lastRpmCalc=millis();
#if ENABLE_BLE
      if(bleUp && bleTx){ bleTx->setValue(statusTxt().c_str()); bleTx->notify(); }
#endif
    } }

  if(leak()) fault("FUITE - ouvrir et secher la capsule");
  if(vBat<V_LOW && millis()>15000){ writeServo(0);
    esp_deep_sleep_enable_gpio_wakeup(1ULL<<PIN_REED,ESP_GPIO_WAKEUP_GPIO_LOW);
    esp_deep_sleep_start(); }
  if(tServo>T_FAULT) fault("Surchauffe servo >65C");

  if(digitalRead(PIN_REED)==LOW){
    if(!reedDown) reedDown=millis();
    if(millis()-reedDown>3000){ writeServo(0);
      esp_deep_sleep_enable_gpio_wakeup(1ULL<<PIN_REED,ESP_GPIO_WAKEUP_GPIO_LOW);
      esp_deep_sleep_start(); }
  } else if(reedDown){
    if(millis()-reedDown<1000){
      if(mode==FAULT_MODE && !leak()){ mode=RUN; stallRetries=0; faultCause=""; }
      else running=!running; }
    reedDown=0; }

  if(mode==FAULT_MODE || !running){ cmdNow=0; writeServo(0); delay(10); return; }

  int capPct=100;
  if(mode==PAUSED_HOT){ cmdNow=0; writeServo(0); if(tServo<T_RESUME) mode=RUN; delay(10); return; }
  if(tServo>T_PAUSE){ mode=PAUSED_HOT; writeServo(0); delay(10); return; }
  if(tServo>T_SOFT) capPct=40;

  int cmd;
  if(remote && millis()-lastCmd<120000) cmd=speedPct;
  else { uint32_t t=millis()%(SWIM_MS+GLIDE_MS); cmd=(t<SWIM_MS)?SWIM_SPEED:0; }
  cmd=constrain(cmd,-capPct,capPct);
  cmdNow=cmd;

  if(abs(cmd)>25 && millis()-lastPulse>STALL_WIN){
    stallRetries++;
    if(stallRetries>3) fault("Rotor bloque/patinage - came et suiveurs");
    else { writeServo(0); delay(400); esp_task_wdt_reset();
           writeServo(-cmd/2); delay(600); esp_task_wdt_reset();
           writeServo(0); delay(200); lastPulse=millis(); } }
  if(millis()-lastPulse<1200) stallRetries=0;

#if ENABLE_LED
  static uint32_t tLed=0;
  if (millis()-tLed>80){ tLed=millis();
    float ph = 2*3.14159f*(millis()%(SWIM_MS+GLIDE_MS))/(float)SWIM_MS;
    ledStatus(mode==FAULT_MODE?2:(mode==PAUSED_HOT?1:0), cmd!=0, ph); }
#endif
  writeServo(cmd);
  delay(10);
}
